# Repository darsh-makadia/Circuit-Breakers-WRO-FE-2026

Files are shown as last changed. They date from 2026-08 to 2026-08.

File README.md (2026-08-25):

# The Dark Knight — Team Current | WRO Future Engineers 2026

> **A reproducible self-driving vehicle developed for WRO Future Engineers 2026**






---

## Contents

- [About the Project](#about-the-project)
- [The Team](#the-team)
- [Final Robot](#final-robot)
- [Hardware and System Overview](#hardware-and-system-overview)
- [Mechanical Design](#mechanical-design)
- [Drivetrain and Differentials](#drivetrain-and-differentials)
- [Steering](#steering)
- [Camera System and Perception](#camera-system-and-perception)
- [Computer Vision Pipeline](#computer-vision-pipeline)
- [Software Architecture](#software-architecture)
- [Open Challenge](#open-challenge)
- [Obstacle Challenge](#obstacle-challenge)
- [Parking Development](#parking-development)
- [Power and Electronics](#power-and-electronics)
- [Testing and Validation](#testing-and-validation)
- [Engineering Evolution](#engineering-evolution)
- [Quick Start](#quick-start)
- [Repository Structure](#repository-structure)
- [Reproducibility](#reproducibility)
- [Evidence Index](#evidence-index)
- [Configuration Consistency](#configuration-consistency)
- [Version and Release](#version-and-release)

---

# About the Project

**The Dark Knight** is Team Current's WRO Future Engineers 2026 self-driving vehicle. The project combines a custom mechanical platform, Raspberry Pi-based control, dual Raspberry Pi Camera Module 3 cameras, colour-based computer vision, an MPU6050 IMU, custom 3D-printed components, and Python software for autonomous navigation.

The robot was developed through multiple mechanical and software iterations rather than as a single fixed design. The repository preserves the final configuration together with the engineering evidence needed to understand how the robot was built, why important design decisions were made, and how the resulting system was tested.

The repository is organised as a connected engineering record:

> **Problem → hypothesis → change → test → measured result → decision**

A judge or another team can begin with this README, follow the construction and setup guides, inspect the source code and CAD/STL files, and then review the photographs, measurements, testing records, engineering evolution, and video evidence.

**Repository:** [Team-Current-WRO-FE-2026](https://github.com/darsh-makadia/Team-Current-WRO-FE-2026)

---

# The Team

<table>
<tr>
<td width="25%" align="center">

Darsh Makadia

### Darsh Makadia
**Team Member**

Mechanical design, hardware integration, software development, testing, and overall robot integration.

</td>
<td width="25%" align="center">

Ehan Mansuri

### Ehan Mansuri
**Team Member**

CAD design, mechanical development, manufactured components, and robot design integration.

</td>
<td width="25%" align="center">

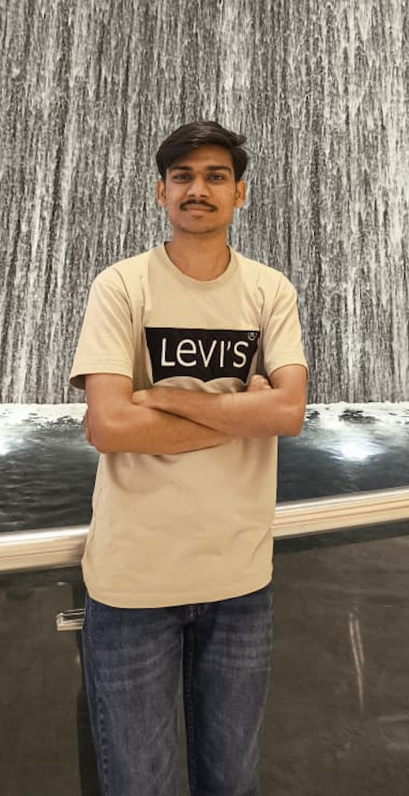
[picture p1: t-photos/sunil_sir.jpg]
Sunil Solanki


### Sunil Solanki
**Coach**

Electrical systems, mechanical guidance, software development, and technical integration guidance.

</td>
<td width="25%" align="center">

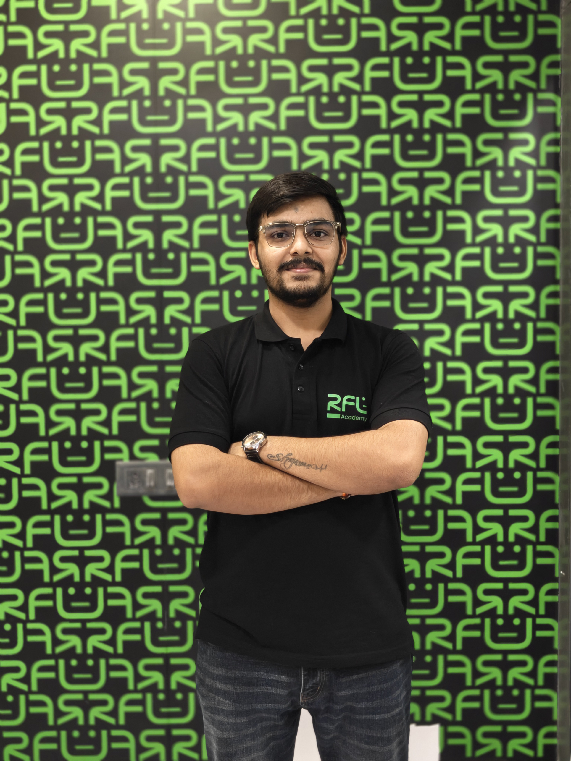
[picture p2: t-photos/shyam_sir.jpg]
Shyam Satasiya


### Shyam Satasiya
**Coach**

CAD guidance and support for mechanical design and manufactured components.

</td>
</tr>
</table>

<p align="center">
Team Current
</p>

---

# Final Robot

The final robot uses a custom 3D-printed chassis and integrates the drivetrain, steering system, cameras, Raspberry Pi, motor electronics, IMU, battery, and electronics enclosure into a compact vehicle.

<table>
<tr>
<td width="33%" align="center">
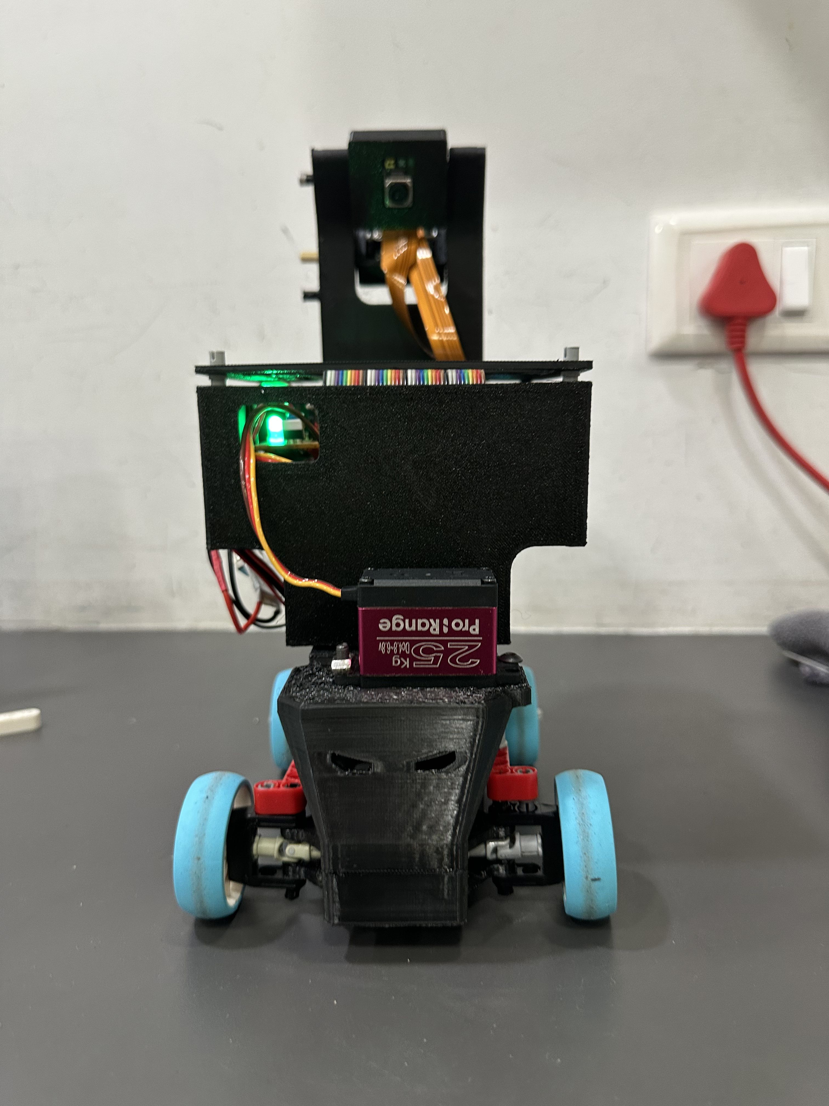
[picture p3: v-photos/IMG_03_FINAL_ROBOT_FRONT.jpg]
Final robot front view

<br><b>Front view</b>
</td>
<td width="33%" align="center">
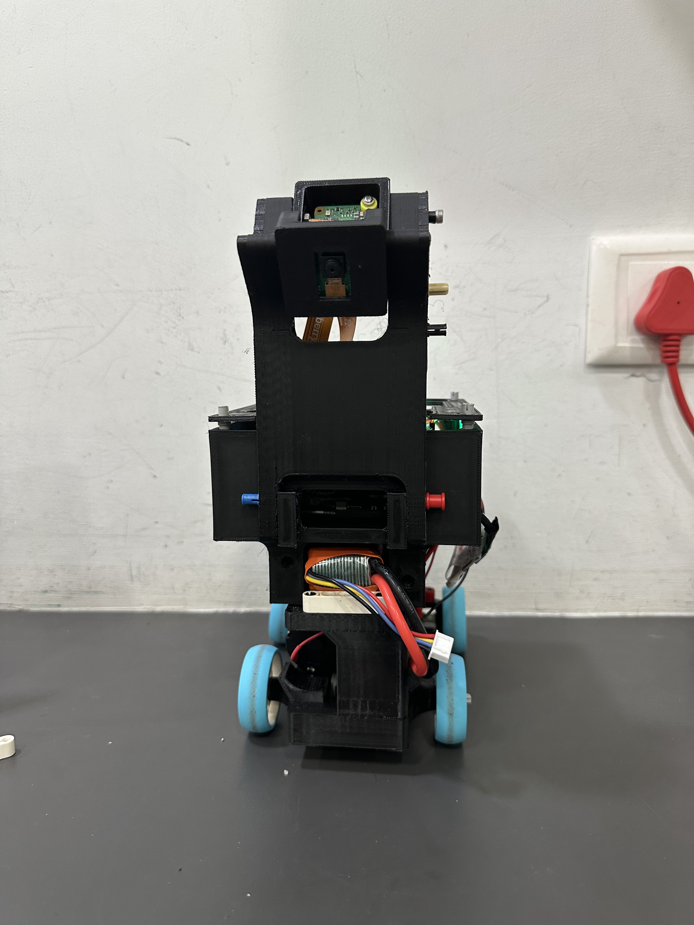
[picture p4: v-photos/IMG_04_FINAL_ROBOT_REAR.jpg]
Final robot rear view

<br><b>Rear view</b>
</td>
<td width="33%" align="center">
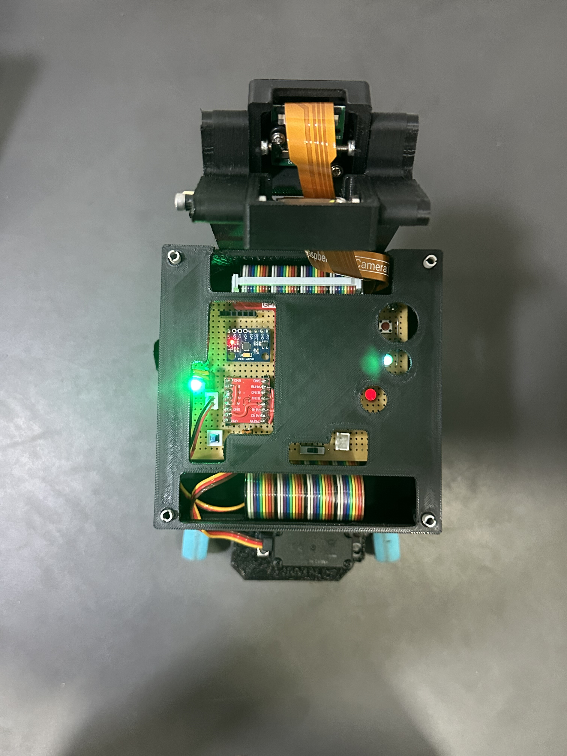
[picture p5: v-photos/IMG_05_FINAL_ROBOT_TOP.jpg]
Final robot top view

<br><b>Top view</b>
</td>
</tr>
</table>

<table>
<tr>
<td width="50%" align="center">
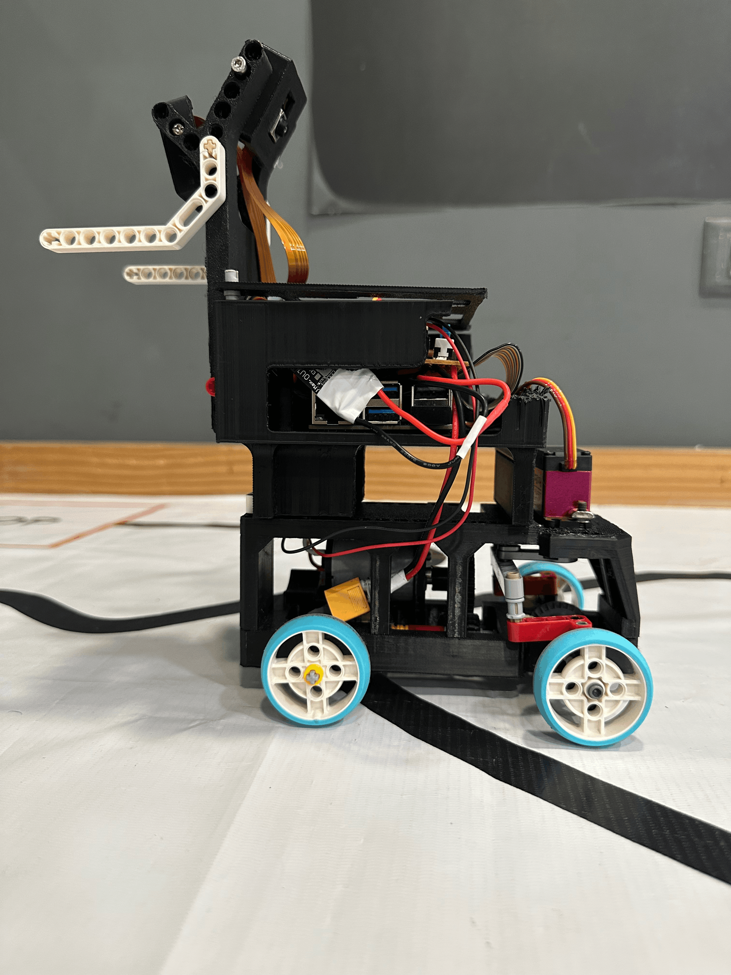
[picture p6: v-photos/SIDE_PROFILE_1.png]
Robot side profile 1

<br><b>Side profile 1</b>
</td>
<td width="50%" align="center">
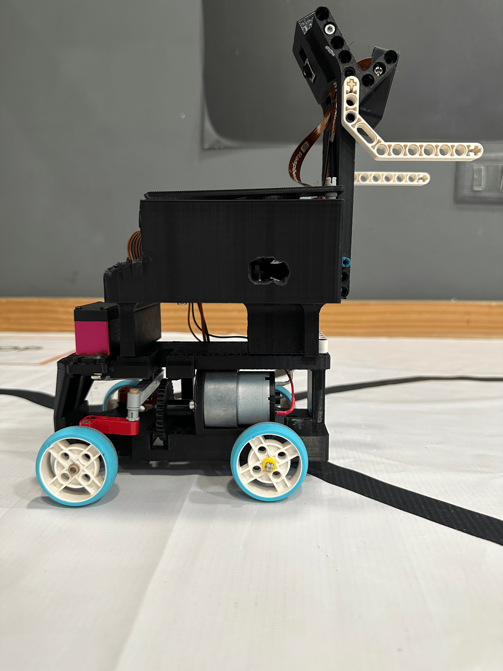
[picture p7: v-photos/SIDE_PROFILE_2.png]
Robot side profile 2

<br><b>Side profile 2</b>
</td>
</tr>
</table>

## Development history

The final configuration was reached through earlier prototypes.

<table>
<tr>
<td width="50%" align="center">
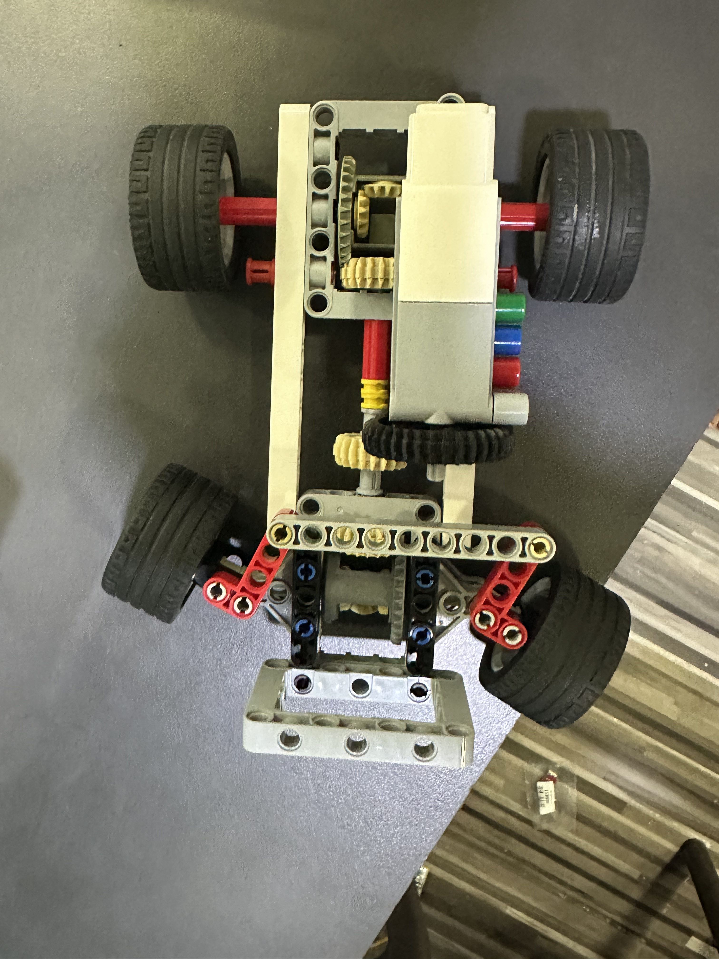
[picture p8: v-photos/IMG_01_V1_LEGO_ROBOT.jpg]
Version 1 LEGO development robot

<br><b>Version 1 — LEGO-heavy development platform</b>
</td>
<td width="50%" align="center">
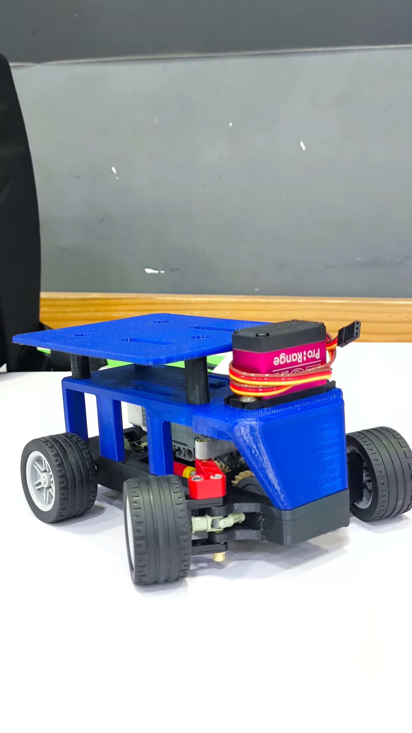
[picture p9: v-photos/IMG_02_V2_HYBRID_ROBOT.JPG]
Version 2 hybrid robot

<br><b>Version 2 — LEGO/CAD hybrid platform</b>
</td>
</tr>
</table>

The progression from a LEGO-heavy prototype to a hybrid platform and then to the final custom chassis is documented in [`testing/engineering_evolution.md`](testing/engineering_evolution.md).

---

# Hardware and System Overview

The robot's main hardware architecture combines:

| Subsystem | Implementation |
|---|---|
| Main computer | Raspberry Pi 5 |
| Cameras | Two Raspberry Pi Camera Module 3 cameras |
| Vision processing | OpenCV-based colour segmentation and contour analysis |
| Heading sensing | MPU6050 through I2C |
| Drive | JGB37-520 DC drive motor |
| Steering | Servo-operated steering mechanism |
| Drivetrain | Central drive arrangement with two axle differentials |
| Battery | 11.1 V battery system |
| Custom components | 3D-printed chassis, camera mount/case, electronics enclosure, and 36-tooth gear |

The exact components and purchase references are documented in [`guide/PARTS_AND_PURCHASE_LINKS.md`](guide/PARTS_AND_PURCHASE_LINKS.md). The construction process is documented in [`guide/BUILD_FROM_ZERO.md`](guide/BUILD_FROM_ZERO.md).

---

# Mechanical Design

The final vehicle uses a custom printed chassis to provide a dedicated structure for the drivetrain, steering system, electronics, cameras, and battery.

## CAD and manufactured components

The final STL files are stored in [`models/`](models/). Their corresponding CAD previews are shown below.

<table>
<tr>
<td width="50%" align="center">
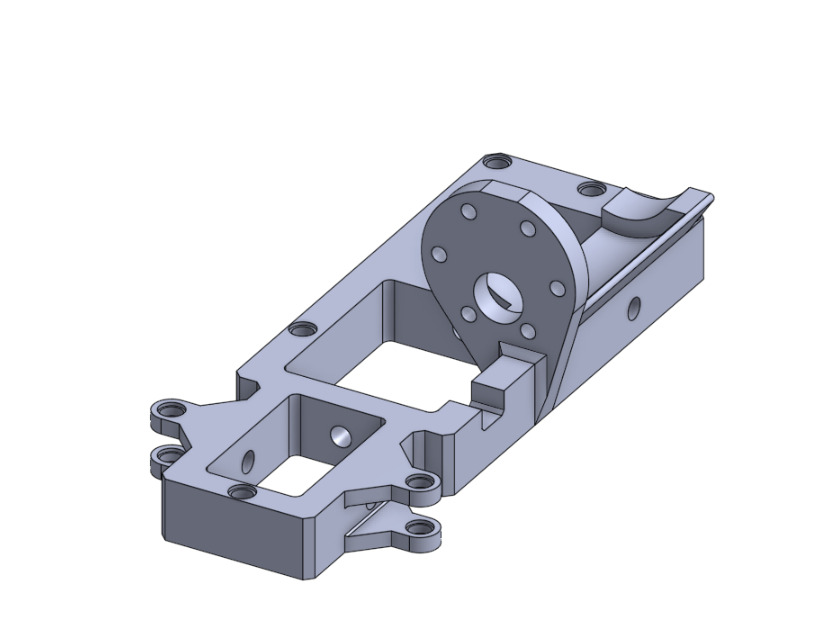
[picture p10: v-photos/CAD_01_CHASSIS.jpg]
CAD chassis

<br><a href="models/chassis.stl"><b>chassis.stl</b></a>
</td>
<td width="50%" align="center">
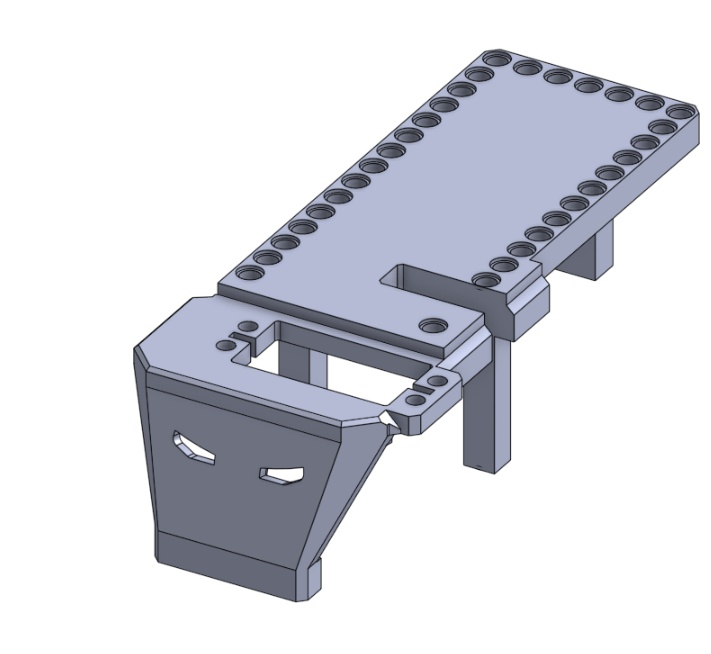
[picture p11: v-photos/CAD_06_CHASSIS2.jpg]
CAD second chassis component

<br><a href="models/chassis%20pt2.stl"><b>chassis pt2.stl</b></a>
</td>
</tr>
<tr>
<td width="50%" align="center">
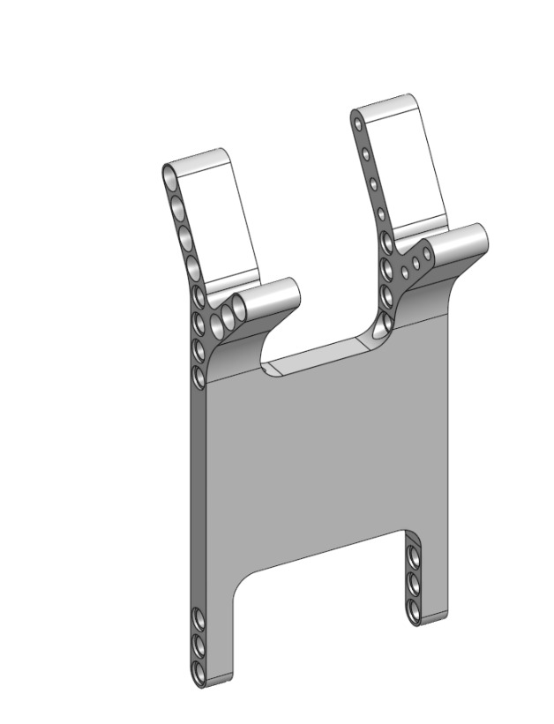
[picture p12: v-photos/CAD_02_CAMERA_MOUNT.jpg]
CAD dual camera mount

<br><a href="models/dual_camera_mount.stl"><b>dual_camera_mount.stl</b></a>
</td>
<td width="50%" align="center">
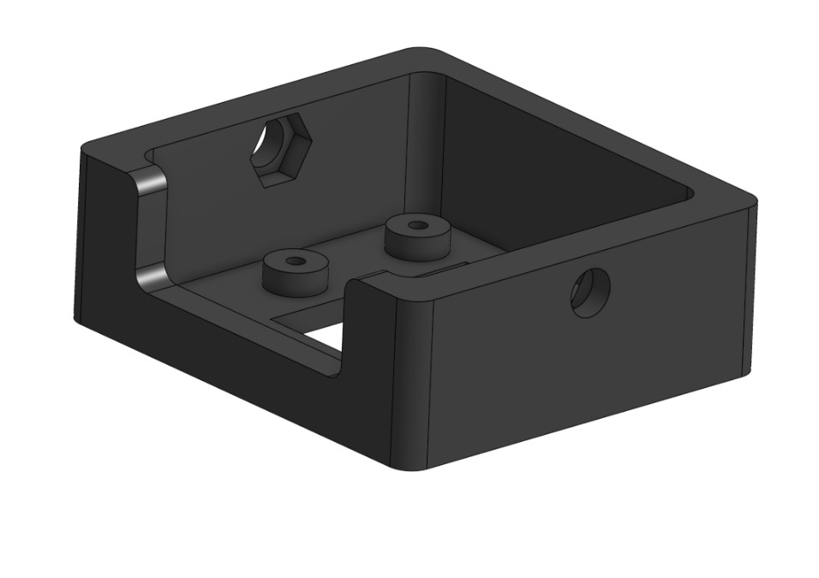
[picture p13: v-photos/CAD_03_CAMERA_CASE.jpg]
CAD camera case

<br><a href="models/camera%20case.stl"><b>camera case.stl</b></a>
</td>
</tr>
<tr>
<td width="50%" align="center">
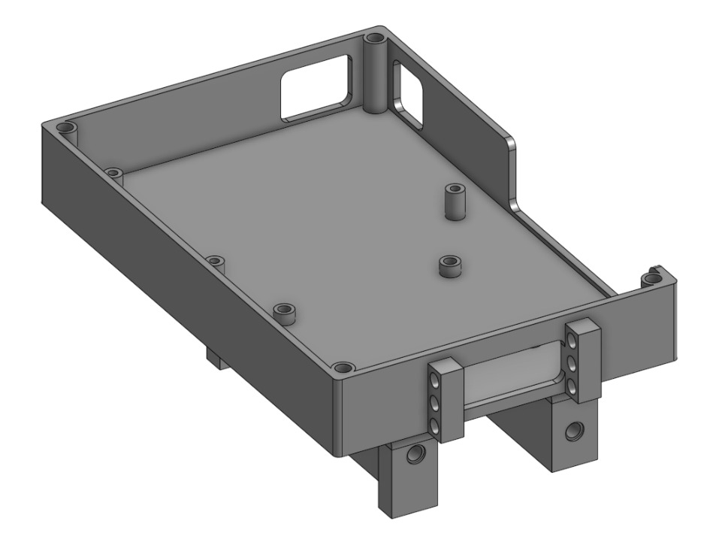
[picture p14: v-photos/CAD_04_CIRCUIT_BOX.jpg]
CAD circuit box

<br><a href="models/Circuit_Box.stl"><b>Circuit_Box.stl</b></a>
</td>
<td width="50%" align="center">
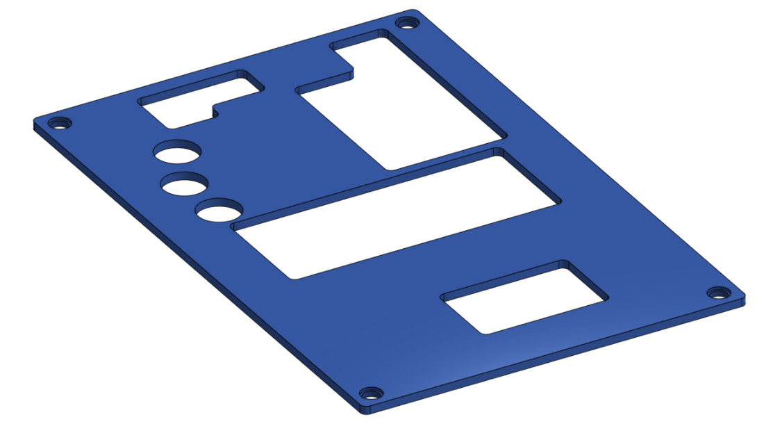
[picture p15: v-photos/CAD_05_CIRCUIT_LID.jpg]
CAD circuit box lid

<br><a href="models/Circuit_Box_LID.stl"><b>Circuit_Box_LID.stl</b></a>
</td>
</tr>
<tr>
<td colspan="2" align="center">
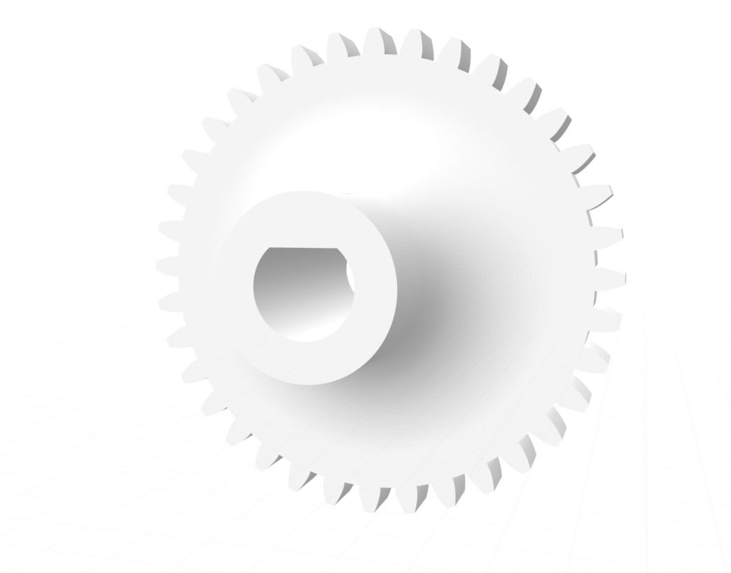
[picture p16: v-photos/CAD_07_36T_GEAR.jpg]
CAD 36 tooth gear

<br><a href="models/36t%20gear.stl"><b>36t gear.stl</b></a>
</td>
</tr>
</table>

Manufacturing settings for the printed components are documented in [`guide/3D_PRINTING_SETTINGS.md`](guide/3D_PRINTING_SETTINGS.md).

---

# Drivetrain and Differentials

The drivetrain uses a central mechanical power path that transfers motion to both axle assemblies. The system includes **two mechanical differentials**, one associated with each axle.

<p align="center">
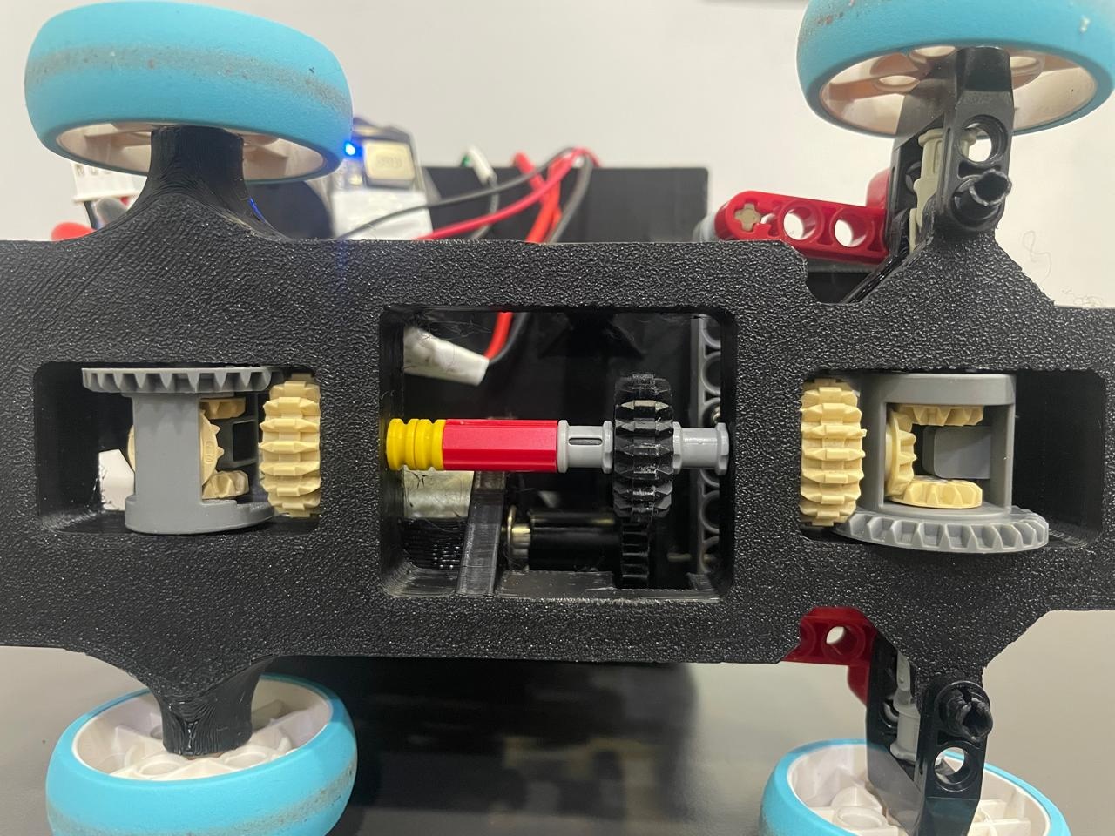
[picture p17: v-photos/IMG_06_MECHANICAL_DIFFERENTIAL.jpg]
Mechanical differential

</p>

The central drivetrain arrangement transfers power through the chassis and distributes it to the axle assemblies.

<p align="center">
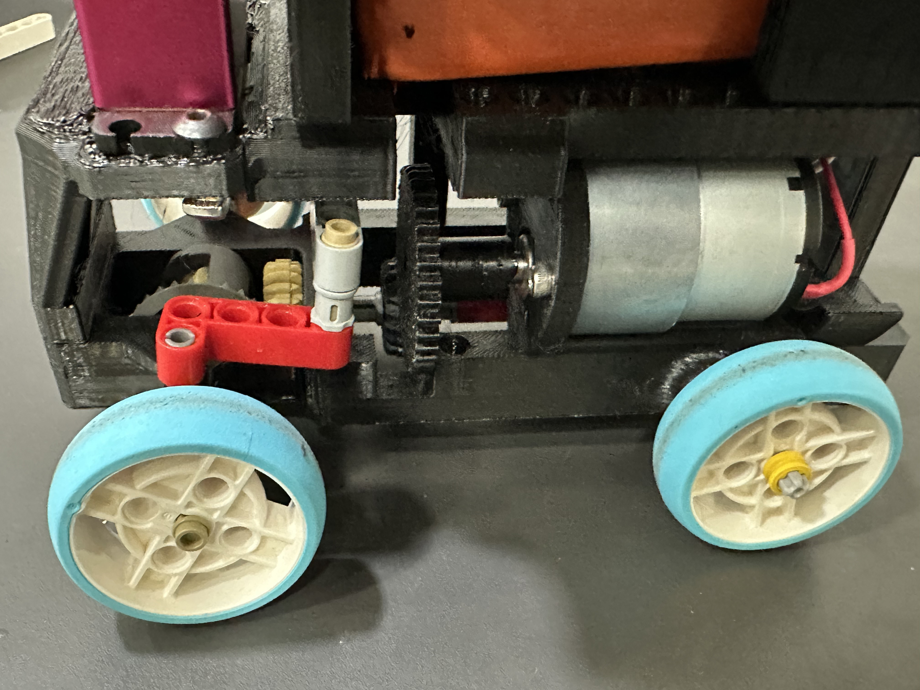
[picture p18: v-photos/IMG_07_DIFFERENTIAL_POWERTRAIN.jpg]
Differential powertrain

</p>

This design allows the drive system to transmit power to all four wheels while retaining differential action at the axle assemblies.

The final drivetrain and motor configuration should be interpreted together with:

- [`guide/BUILD_FROM_ZERO.md`](guide/BUILD_FROM_ZERO.md)
- [`guide/PARTS_AND_PURCHASE_LINKS.md`](guide/PARTS_AND_PURCHASE_LINKS.md)
- [`testing/engineering_evolution.md`](testing/engineering_evolution.md)

---

# Steering

Steering is controlled by a servo-driven mechanical linkage. The steering system was calibrated on the physical robot and integrated with the vehicle-control functions in [`src/drive.py`](src/drive.py).

<p align="center">
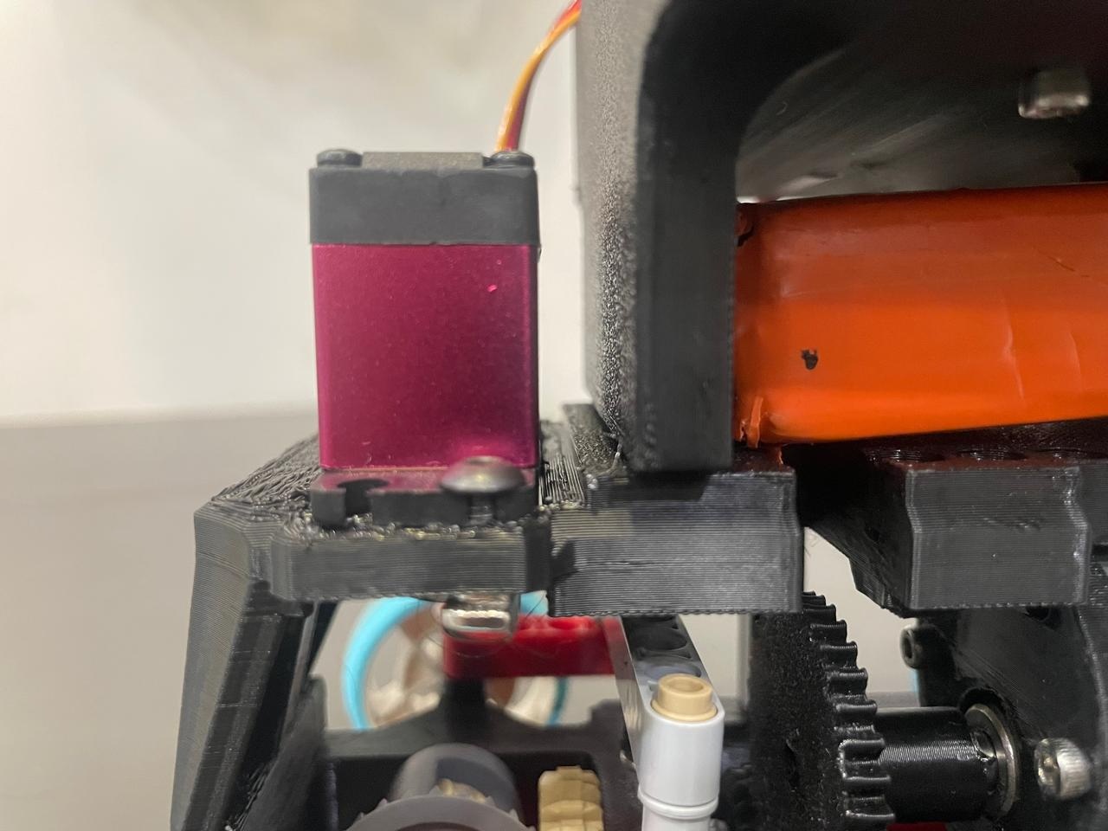
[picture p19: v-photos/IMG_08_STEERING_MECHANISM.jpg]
Steering mechanism

</p>

The software provides steering limits, movement commands, stop behaviour, and GPIO cleanup. Final steering values are controlled by the source configuration and should be verified against the physical robot before a new reproduction or competition configuration is called final.

The drive motor mounting arrangement is shown below.

<p align="center">
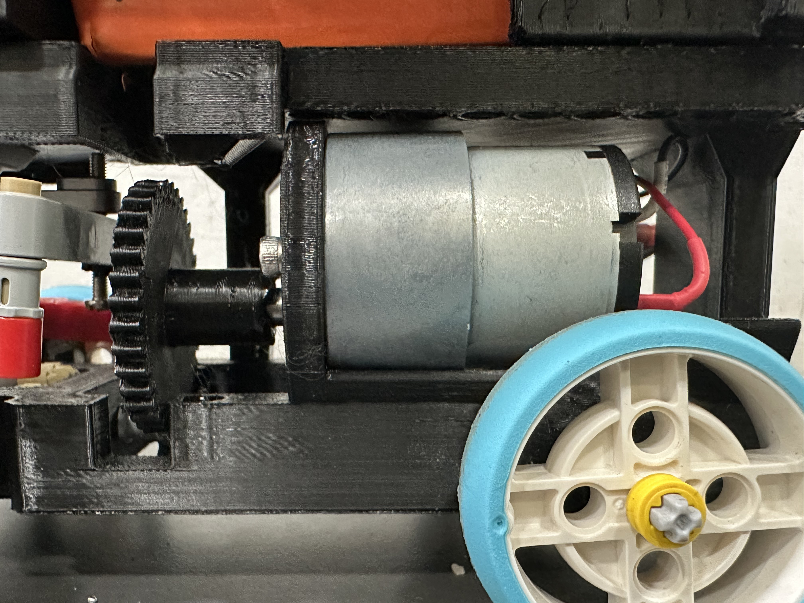
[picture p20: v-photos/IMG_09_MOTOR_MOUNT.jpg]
Motor mount

</p>

---

# Camera System and Perception

The robot uses two Raspberry Pi Camera Module 3 cameras for different perception tasks.

<p align="center">
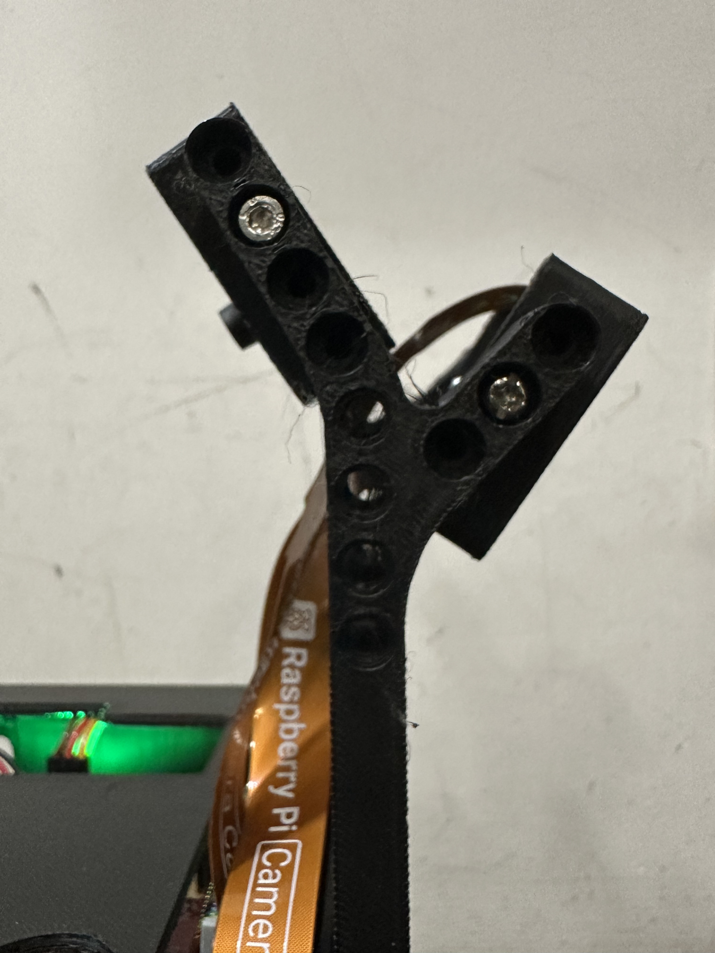
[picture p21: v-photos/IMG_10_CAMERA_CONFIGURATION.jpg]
Camera configuration

</p>

The camera mounting system was adjusted during development to obtain useful fields of view for challenge navigation and parking.

<p align="center">
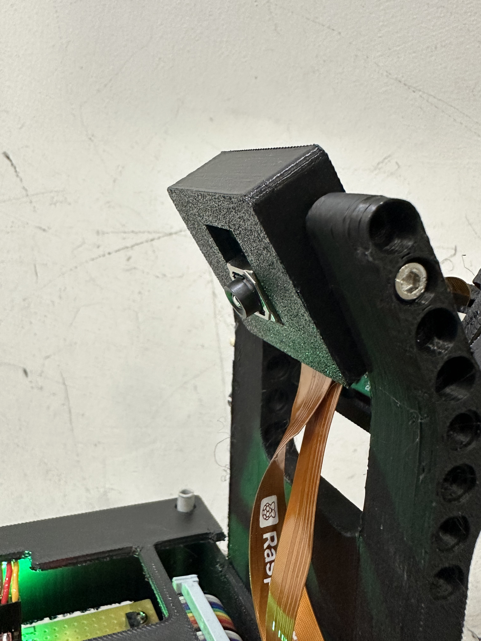
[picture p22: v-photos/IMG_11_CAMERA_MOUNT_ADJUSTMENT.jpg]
Camera mount adjustment

</p>

## Camera evidence

<table>
<tr>
<td width="33%" align="center">
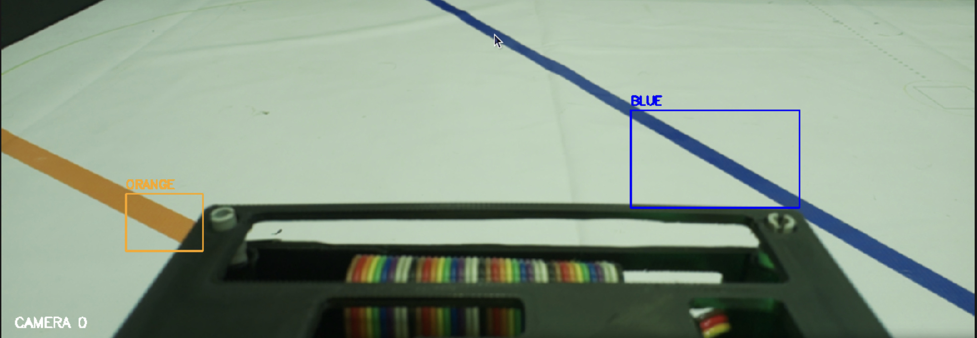
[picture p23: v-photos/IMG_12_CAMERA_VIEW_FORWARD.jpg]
Forward camera view

<br><b>Forward navigation view</b>
</td>
<td width="33%" align="center">
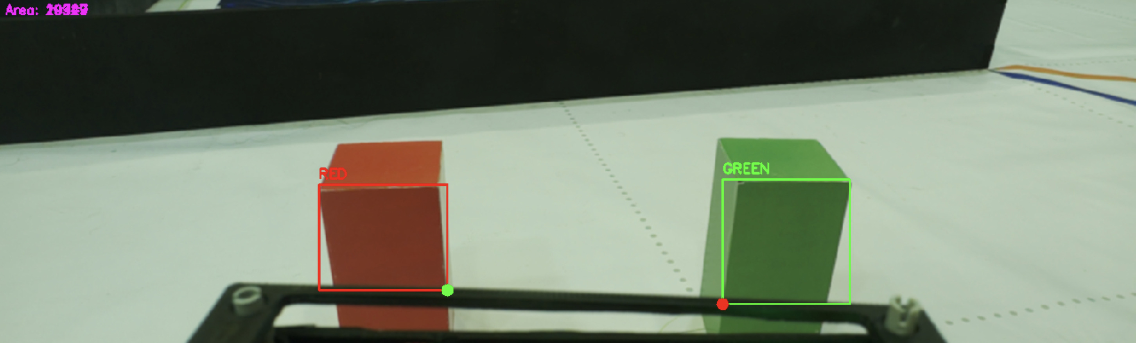
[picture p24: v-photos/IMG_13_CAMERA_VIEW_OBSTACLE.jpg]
Obstacle camera view

<br><b>Obstacle perception view</b>
</td>
<td width="33%" align="center">
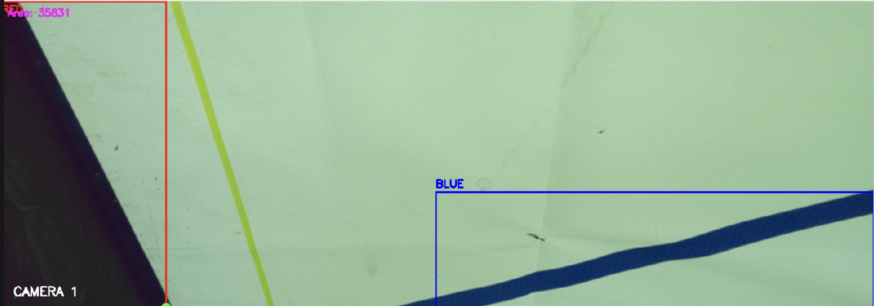
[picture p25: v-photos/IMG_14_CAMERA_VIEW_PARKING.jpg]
Parking camera view

<br><b>Parking perception view</b>
</td>
</tr>
</table>

Both challenge programs currently use the front camera at **1480 × 520 pixels**. The configured target and the measured processing performance are kept separate: the target camera rate is not presented as identical to the observed end-to-end processing rate.

Camera and sensor configuration evidence is documented in [`guide/POWER_AND_SENSOR_EVIDENCE.md`](guide/POWER_AND_SENSOR_EVIDENCE.md).

---

# Computer Vision Pipeline

The vision implementation is based primarily on direct colour segmentation and contour analysis using OpenCV.

The shared processing sequence is:

```text
Camera frame
    ↓
HSV conversion
    ↓
Colour mask
    ↓
Morphological opening/closing
    ↓
Contour extraction
    ↓
Filtering / confidence logic
    ↓
Target point
```

## Open Challenge processing

The Open Challenge uses the relevant camera image and marker-processing logic to determine direction, detect and count markers, support wall following, and determine when the configured challenge sequence is complete.

The Open Challenge-specific vision implementation is contained in [`src/openVision.py`](src/openVision.py), while the main challenge program is [`src/Current_Open_8_22.py`](src/Current_Open_8_22.py).

## Obstacle Challenge processing

The Obstacle Challenge uses colour segmentation and contour processing to identify coloured obstacles and calculate the target information used by the challenge-control logic.

A black segmentation mask is used as evidence for track/boundary isolation:

<p align="center">
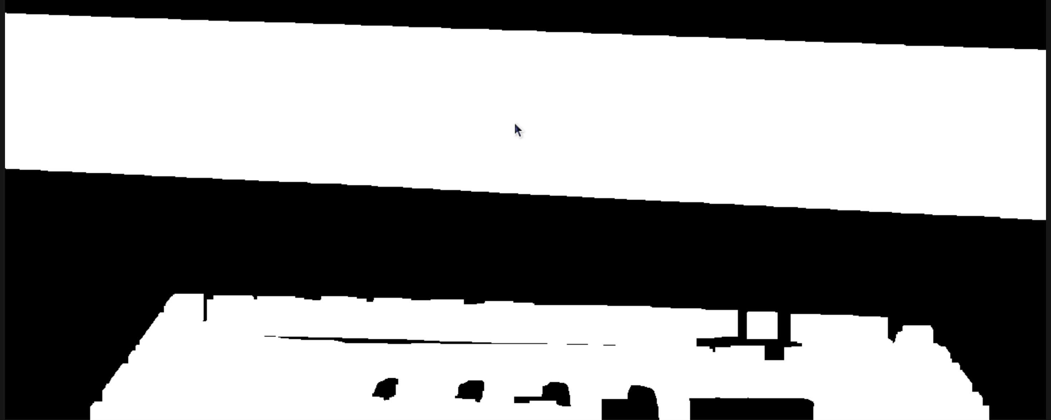
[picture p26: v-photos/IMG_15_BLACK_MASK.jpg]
Black segmentation mask

</p>

Contour processing and obstacle detection evidence are shown below.

<table>
<tr>
<td width="50%" align="center">
Contour detection
<br><b>Contour-processing output</b>
</td>
<td width="50%" align="center">
Obstacle detection
<br><b>Obstacle-detection output</b>
</td>
</tr>
</table>

The shared obstacle-processing implementation is contained in [`src/vision.py`](src/vision.py), while challenge behaviour is controlled by [`src/Current_Obstacle_8_21.py`](src/Current_Obstacle_8_21.py).

---

# Software Architecture

The repository contains the executable Python programs and reusable hardware/software modules in [`src/`](src/).

| File | Function |
|---|---|
| [`Current_Open_8_22.py`](src/Current_Open_8_22.py) | Open Challenge program, direction selection, marker detection/counting, wall following, steering, speed control, and stopping. |
| [`Current_Obstacle_8_21.py`](src/Current_Obstacle_8_21.py) | Obstacle Challenge program, colour-obstacle detection, direction-dependent avoidance, lap/parking transition, and completion behaviour. |
| [`drive.py`](src/drive.py) | Raspberry Pi GPIO motor control, PWM, forward/reverse movement, servo steering, steering limits, stop, and cleanup. |
| [`heading.py`](src/heading.py) | MPU6050 I2C communication, gyro-bias calibration, heading integration, and heading wrapping. |
| [`vision.py`](src/vision.py) | Shared camera processing, colour masks, morphology, contour detection, confidence logic, and target selection. |
| [`openVision.py`](src/openVision.py) | Open Challenge-specific vision processing. |
| [`parking.py`](src/parking.py) | Rear-camera parking detection, wall following, and IMU-guided parking actions. |

The GPIO implementation uses **`RPi.GPIO`**, as reflected by the source import:

```python
import RPi.GPIO as GPIO
```

The MPU6050 communicates through **I2C**.

The repository intentionally lists the actual source filenames rather than generic names such as `open_challenge.py` or `obstacle_challenge.py`. A reproducible configuration should always run and document the source files that actually exist in the final repository.

---

# WRO Challenges

## Open Challenge

The Open Challenge software is implemented in:

[`src/Current_Open_8_22.py`](src/Current_Open_8_22.py)

The program combines:

- direction selection;
- marker detection and counting;
- cooldown and duplicate-detection control;
- wall-following logic;
- steering control;
- speed control; and
- challenge completion/stopping behaviour.

The current source contains the final challenge parameters used for the repository baseline, including:

- `TOTAL_LINES = 13`
- `LINE_COOLDOWN = 1.2`
- `START_SPEED = 40`
- `TARGET_SPEED = 70`

These values should not be replaced in documentation by older values unless the source itself is changed and the resulting configuration is retested.

### Open Challenge evidence

<p align="center">
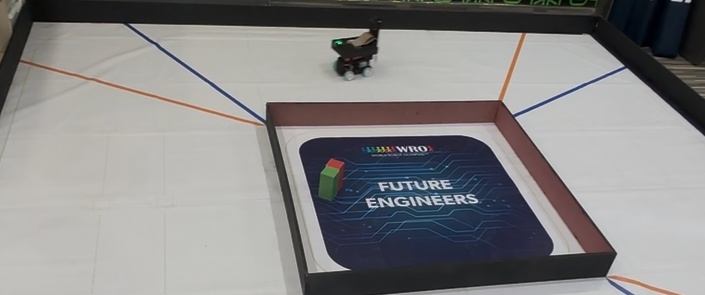
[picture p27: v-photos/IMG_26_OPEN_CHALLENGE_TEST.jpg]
Open Challenge test

</p>

The repository also contains an Open Challenge video in [`testing/Open_Challenge.mp4`](testing/Open_Challenge.mp4) and additional video evidence in [`video/`](video/).

---

## Obstacle Challenge

The Obstacle Challenge software is implemented in:

[`src/Current_Obstacle_8_21.py`](src/Current_Obstacle_8_21.py)

The challenge program combines colour-based obstacle perception with direction-dependent navigation and vehicle control. Supporting functions are provided by the shared vision, drive, and heading modules.

<p align="center">
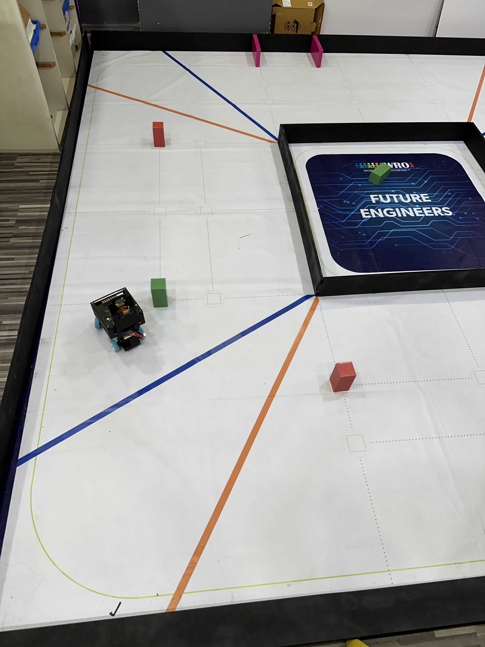
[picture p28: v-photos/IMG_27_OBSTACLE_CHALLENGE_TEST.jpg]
Obstacle Challenge test

</p>

Individual challenge results and observations are stored in [`testing/test_results.csv`](testing/test_results.csv), with a readable summary in [`testing/test_summary.md`](testing/test_summary.md).

Measured processing observations are stored separately in [`testing/processing_observations.csv`](testing/processing_observations.csv). These observations should be interpreted according to the recorded robot configuration and test conditions rather than as a guarantee of an identical processing rate under every possible operating condition.

---

# Parking Development

Parking is an active engineering component of the robot and is represented by:

- [`src/parking.py`](src/parking.py)
- the rear-camera parking view;
- IMU-guided parking actions; and
- dedicated parking test evidence.

<p align="center">
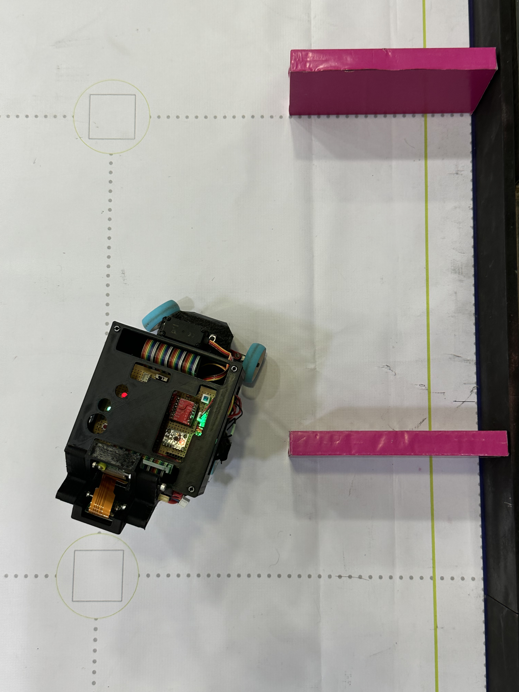
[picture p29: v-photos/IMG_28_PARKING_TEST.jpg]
Parking test

</p>

The parking subsystem is **not presented in this repository as a fully validated final challenge sequence**. Development and testing evidence are retained so that the current implementation, observations, and remaining work are traceable.

Where challenge performance tables or videos exclude parking, they should be interpreted as measuring the completed sequence **up to the parking stage or parking approach**, rather than as proof of a complete run including parallel parking.

This distinction is important for configuration honesty:

> A working Open Challenge and a working obstacle-navigation sequence do not by themselves prove a fully completed Obstacle Challenge with parking.

The current parking implementation and its development evidence remain available for inspection and further improvement.

---

# Power and Electronics

The electrical system distributes power to the Raspberry Pi and logic electronics separately from the motor-control branch.

<p align="center">
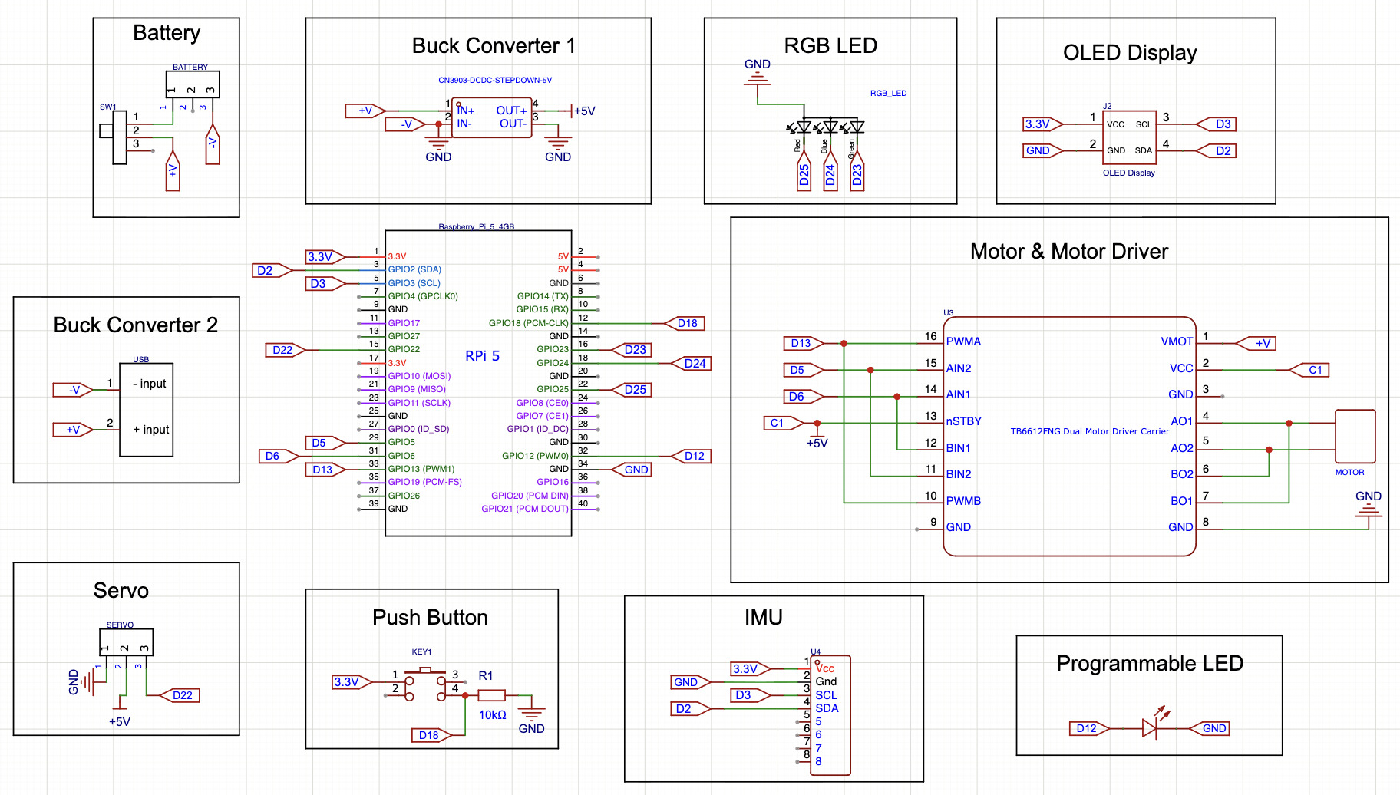
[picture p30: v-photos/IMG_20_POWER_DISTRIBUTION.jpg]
Power distribution

</p>

The electronics enclosure protects and organises the internal components.

<table>
<tr>
<td width="50%" align="center">
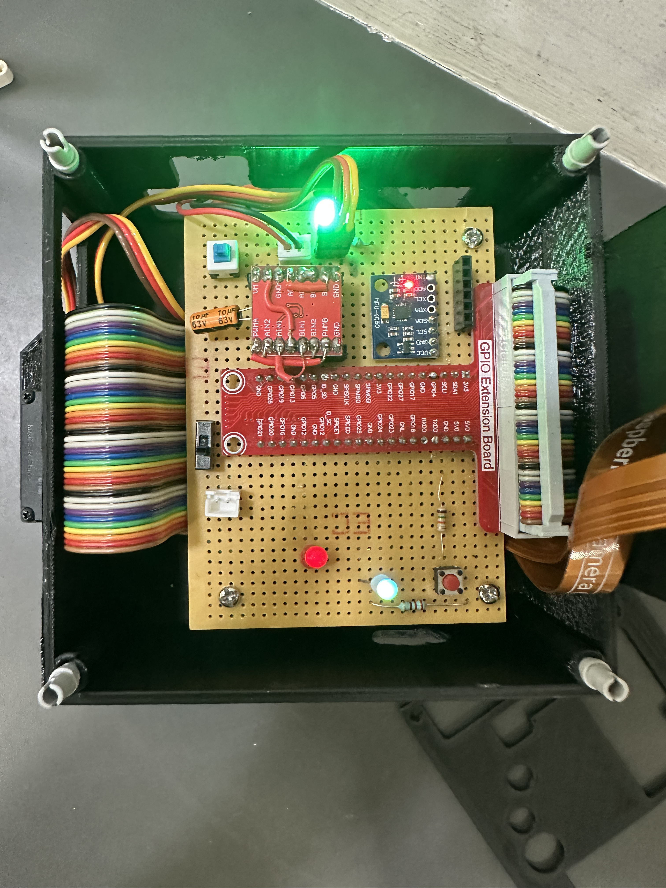
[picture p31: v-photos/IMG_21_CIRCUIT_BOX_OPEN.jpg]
Open circuit box

<br><b>Electronics enclosure — open</b>
</td>
<td width="50%" align="center">
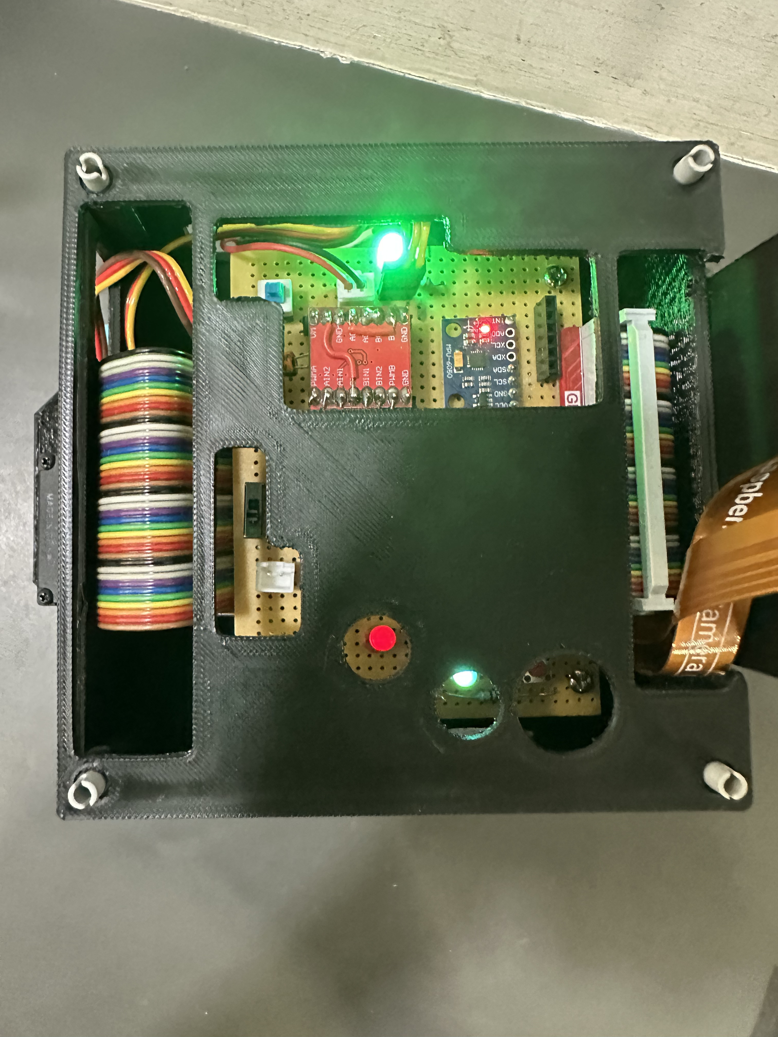
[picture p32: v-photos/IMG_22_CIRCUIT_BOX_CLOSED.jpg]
Closed circuit box

<br><b>Electronics enclosure — closed</b>
</td>
</tr>
</table>

The battery installation is shown below.

<p align="center">
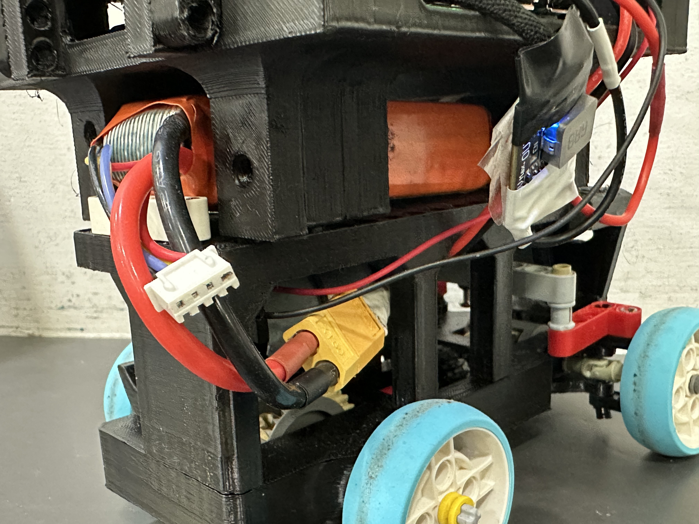
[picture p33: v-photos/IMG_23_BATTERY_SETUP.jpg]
Battery setup

</p>

The final electrical schematic is the primary visual reference for power distribution and signal connections:

<p align="center">
<a href="schemes/schematic.jpg">
Electrical schematic
</a>
</p>

For detailed electrical reproduction, use:

- [`schemes/schematic.jpg`](schemes/schematic.jpg)
- [`guide/WIRING_AND_PIN_REFERENCE.md`](guide/WIRING_AND_PIN_REFERENCE.md)
- [`guide/POWER_AND_SENSOR_EVIDENCE.md`](guide/POWER_AND_SENSOR_EVIDENCE.md)
- [`testing/power_measurements.csv`](testing/power_measurements.csv)

Measured voltages and any current values that were not directly measured are explicitly distinguished in the power evidence rather than being presented as equivalent measurements.

---

# Testing and Validation

Testing evidence is stored in [`testing/`](testing/).

The validation workflow is:

```text
Problem
    ↓
Hypothesis
    ↓
Engineering change
    ↓
Test
    ↓
Measured result
    ↓
Decision
```

## Test records

| File | Evidence |
|---|---|
| [`test_results.csv`](testing/test_results.csv) | Individual Open Challenge and Obstacle Challenge runs, times, and observations. |
| [`test_summary.md`](testing/test_summary.md) | Human-readable summary of challenge results and processing observations. |
| [`engineering_evolution.md`](testing/engineering_evolution.md) | Problems encountered, engineering changes, tests, and resulting decisions. |
| [`power_measurements.csv`](testing/power_measurements.csv) | Measured voltage data and explicit identification of current values that were not directly measured. |
| [`processing_observations.csv`](testing/processing_observations.csv) | Camera FPS, processing loop rate, capture latency, and processing latency observations. |
| [`Open_Challenge.mp4`](testing/Open_Challenge.mp4) | Open Challenge test video stored with testing evidence. |

## Interpreting results correctly

A result is meaningful only within its recorded configuration and conditions. Battery condition, robot configuration, software version, challenge direction, obstacle placement, and test procedure can affect results.

Therefore:

- measurements from different hardware configurations are not automatically treated as identical trials;
- different obstacle placements are not treated as identical challenge conditions;
- configured target rates are not treated as identical to measured end-to-end rates;
- unmeasured current estimates are not presented as direct measurements; and
- performance evidence that excludes parking is not presented as proof of a complete parked sequence.

This distinction is part of the repository's reproducibility standard.

---

# Engineering Evolution

The robot developed through multiple iterations of mechanical, electrical, perception, and software design.

The visual progression is documented from the earlier development platforms to the final robot:

<p align="center">
Version 1
Version 2
Final robot
</p>

The complete engineering record is maintained in [`testing/engineering_evolution.md`](testing/engineering_evolution.md).

This file should be used to trace the important design changes, including mechanical redesign, camera changes, power architecture, steering calibration, vision development, and parking development.

---

# Quick Start

> The exact Raspberry Pi OS version should be confirmed from the final physical robot before a clean reproduction is declared complete.

## 1. Start with the repository guide

Read:

[`guide/START_HERE.md`](guide/START_HERE.md)

This provides the recommended reading order and repository map.

## 2. Obtain the required components

Use:

[`guide/PARTS_AND_PURCHASE_LINKS.md`](guide/PARTS_AND_PURCHASE_LINKS.md)

and verify the final component list against:

[`guide/PARTS_CHECKLIST.md`](guide/PARTS_CHECKLIST.md)

If one file is explicitly designated as the authoritative final list in the repository, that designation should take precedence.

## 3. Build the mechanical platform

Follow:

[`guide/BUILD_FROM_ZERO.md`](guide/BUILD_FROM_ZERO.md)

Download the manufactured part files from:

[`models/`](models/)

Use the documented printing settings in:

[`guide/3D_PRINTING_SETTINGS.md`](guide/3D_PRINTING_SETTINGS.md)

## 4. Complete the electrical system

Use:

- [`schemes/schematic.jpg`](schemes/schematic.jpg)
- [`guide/WIRING_AND_PIN_REFERENCE.md`](guide/WIRING_AND_PIN_REFERENCE.md)

The schematic and pin reference should be checked together rather than treating one image as a complete substitute for the detailed wiring guide.

## 5. Prepare the Raspberry Pi

The source uses:

- Raspberry Pi 5;
- Raspberry Pi Camera Module 3 cameras;
- Python;
- OpenCV;
- NumPy;
- Picamera2;
- `RPi.GPIO`;
- `smbus2`; and
- I2C communication with the MPU6050.

The complete setup procedure belongs in:

[`guide/SOFTWARE_SETUP.md`](guide/SOFTWARE_SETUP.md)

To enable I2C on a fresh Raspberry Pi OS installation:

```bash
sudo raspi-config
```

Then select:

```text
Interface Options → I2C → Enable
```

Reboot after enabling the interface.

The exact Raspberry Pi OS release used for the final configuration can be checked with:

```bash
cat /etc/os-release
```

That version should be copied into the software setup documentation only after it is verified on the physical robot.

## 6. Calibrate and test

Before a challenge run:

1. verify both camera connections;
2. verify I2C communication with the MPU6050;
3. calibrate steering;
4. calibrate the gyro bias and heading behaviour;
5. verify colour-detection thresholds;
6. perform a stationary motor and steering test;
7. perform an Open Challenge test;
8. perform an Obstacle Challenge test; and
9. compare observations with the records in [`testing/`](testing/).

---

# Repository Structure

```text
Team-Current-WRO-FE-2026/
├── README.md
├── CHANGELOG.md
├── .gitattributes
├── .gitignore
│
├── guide/
│   ├── 3D_PRINTING_SETTINGS.md
│   ├── BUILD_FROM_ZERO.md
│   ├── PARTS_AND_PURCHASE_LINKS.md
│   ├── PARTS_CHECKLIST.md
│   ├── POWER_AND_SENSOR_EVIDENCE.md
│   ├── REPRODUCIBILITY_AND_RELEASE_EVIDENCE.md
│   ├── SOFTWARE_SETUP.md
│   ├── START_HERE.md
│   └── WIRING_AND_PIN_REFERENCE.md
│
├── models/
├── schemes/
├── src/
├── testing/
├── t-photos/
├── v-photos/
└── video/
```

## Judge reading path

The recommended path through the repository is:

```text
README.md
→ guide/START_HERE.md
→ guide/BUILD_FROM_ZERO.md
→ guide/PARTS_AND_PURCHASE_LINKS.md
→ guide/WIRING_AND_PIN_REFERENCE.md
→ guide/SOFTWARE_SETUP.md
→ src/
→ models/
→ schemes/schematic.jpg
→ v-photos/
→ testing/
→ video/
→ CHANGELOG.md
```

---

# Detailed Repository Map

## `guide/`

| File | Purpose |
|---|---|
| [`START_HERE.md`](guide/START_HERE.md) | Recommended reading order and repository map. |
| [`BUILD_FROM_ZERO.md`](guide/BUILD_FROM_ZERO.md) | Robot assembly from the parts through testing priorities. |
| [`PARTS_AND_PURCHASE_LINKS.md`](guide/PARTS_AND_PURCHASE_LINKS.md) | Required components and purchase references. |
| [`PARTS_CHECKLIST.md`](guide/PARTS_CHECKLIST.md) | Component checklist. |
| [`WIRING_AND_PIN_REFERENCE.md`](guide/WIRING_AND_PIN_REFERENCE.md) | Power architecture, GPIO assignments, motor-driver connections, servo connection, I2C devices, cameras, steering values, and measured voltages. |
| [`SOFTWARE_SETUP.md`](guide/SOFTWARE_SETUP.md) | Raspberry Pi setup, dependencies, cameras, I2C, source map, calibration, run order, and safety instructions. |
| [`POWER_AND_SENSOR_EVIDENCE.md`](guide/POWER_AND_SENSOR_EVIDENCE.md) | Power branches, voltage evidence, current limitations, sensor selection, calibration, and interference considerations. |
| [`3D_PRINTING_SETTINGS.md`](guide/3D_PRINTING_SETTINGS.md) | Manufacturing settings for custom printed components. |
| [`REPRODUCIBILITY_AND_RELEASE_EVIDENCE.md`](guide/REPRODUCIBILITY_AND_RELEASE_EVIDENCE.md) | Configuration baseline, clean-build workflow, evidence mapping, and release discipline. |

## `models/`

| STL file | Purpose |
|---|---|
| [`chassis.stl`](models/chassis.stl) | Main custom printed chassis. |
| [`chassis pt2.stl`](models/chassis%20pt2.stl) | Additional chassis component. |
| [`dual_camera_mount.stl`](models/dual_camera_mount.stl) | Dual-camera mounting structure. |
| [`camera case.stl`](models/camera%20case.stl) | Camera enclosure. |
| [`Circuit_Box.stl`](models/Circuit_Box.stl) | Electronics enclosure. |
| [`Circuit_Box_LID.stl`](models/Circuit_Box_LID.stl) | Electronics-enclosure lid. |
| [`36t gear.stl`](models/36t%20gear.stl) | Custom 36-tooth drive gear. |

## `schemes/`

| File | Purpose |
|---|---|
| [`schematic.jpg`](schemes/schematic.jpg) | Final electrical schematic and primary visual reference for power and signal connections. |

## `src/`

The executable source code is described in the [Software Architecture](#software-architecture) section above.

## `testing/`

The testing records are described in the [Testing and Validation](#testing-and-validation) section above.

## `t-photos/`

Contains team and individual photographs used in the [Team](#the-team) section.

## `v-photos/`

Contains CAD previews, robot photographs, mechanical evidence, camera/perception evidence, power/electronics evidence, and challenge-testing photographs.

## `video/`

Contains additional local challenge video evidence and [`yt_video_link.md`](video/yt_video_link.md), which identifies the external YouTube video evidence.

---

# Reproducibility

The repository is intended to allow another team or reviewer to trace the final robot from design through validation.

A reproducible reconstruction should be able to follow:

```text
Parts
  ↓
CAD/STL manufacturing
  ↓
Mechanical assembly
  ↓
Electrical schematic and pin wiring
  ↓
Raspberry Pi and software setup
  ↓
Sensor and steering calibration
  ↓
Source-code execution
  ↓
Challenge testing
  ↓
Comparison with recorded evidence
```

The detailed reproducibility procedure is maintained in:

[`guide/REPRODUCIBILITY_AND_RELEASE_EVIDENCE.md`](guide/REPRODUCIBILITY_AND_RELEASE_EVIDENCE.md)

The most important reproducibility principle is:

> **The README, engineering journal, guide files, source code, CAD/STL files, schematic, testing records, and changelog must describe the same final robot configuration. If a parameter or hardware component changes during development, the corresponding source, test record, and documentation are updated together before the configuration is called final.**

The repository therefore treats documentation as part of the engineering configuration rather than as a separate description written after development.

---

# Failure Modes and Mitigation

| Failure mode | Mitigation or engineering response |
|---|---|
| IMU or I2C communication failure | Stop or prevent an uncontrolled manoeuvre according to the implemented safety behaviour. |
| Duplicate marker detection | Use rising-edge detection and a cooldown period. |
| Camera exposure variation | Use the documented exposure and camera configuration procedures. |
| False colour detection | Use colour masks, morphology, contour filtering, geometry/confidence logic, and challenge-specific validation. |
| Motor stall or excessive current | Use the documented motor/power configuration and distinguish measured electrical values from estimates. |
| Excessive speed or wheel lift | Tune operating speed for stability rather than relying on theoretical maximum motor RPM. |
| Wall collision | Record the remaining risk and refine direction-dependent navigation and steering behaviour. |
| Low battery condition | Verify battery condition and documented voltage thresholds before testing. |
| Parking instability | Treat parking as a separate development limitation until the complete sequence is validated. |

Failure handling and engineering limitations should remain consistent across the source code, test records, README, and engineering journal.

---

# Evidence Index

## Final robot and development

- [`IMG_01_V1_LEGO_ROBOT.jpg`](v-photos/IMG_01_V1_LEGO_ROBOT.jpg)
- [`IMG_02_V2_HYBRID_ROBOT.JPG`](v-photos/IMG_02_V2_HYBRID_ROBOT.JPG)
- [`IMG_03_FINAL_ROBOT_FRONT.jpg`](v-photos/IMG_03_FINAL_ROBOT_FRONT.jpg)
- [`IMG_04_FINAL_ROBOT_REAR.jpg`](v-photos/IMG_04_FINAL_ROBOT_REAR.jpg)
- [`IMG_05_FINAL_ROBOT_TOP.jpg`](v-photos/IMG_05_FINAL_ROBOT_TOP.jpg)
- [`SIDE_PROFILE_1.png`](v-photos/SIDE_PROFILE_1.png)
- [`SIDE_PROFILE_2.png`](v-photos/SIDE_PROFILE_2.png)

## Mechanical evidence

- [`IMG_06_MECHANICAL_DIFFERENTIAL.jpg`](v-photos/IMG_06_MECHANICAL_DIFFERENTIAL.jpg)
- [`IMG_07_DIFFERENTIAL_POWERTRAIN.jpg`](v-photos/IMG_07_DIFFERENTIAL_POWERTRAIN.jpg)
- [`IMG_08_STEERING_MECHANISM.jpg`](v-photos/IMG_08_STEERING_MECHANISM.jpg)
- [`IMG_09_MOTOR_MOUNT.jpg`](v-photos/IMG_09_MOTOR_MOUNT.jpg)

## Camera and perception evidence

- [`IMG_10_CAMERA_CONFIGURATION.jpg`](v-photos/IMG_10_CAMERA_CONFIGURATION.jpg)
- [`IMG_11_CAMERA_MOUNT_ADJUSTMENT.jpg`](v-photos/IMG_11_CAMERA_MOUNT_ADJUSTMENT.jpg)
- [`IMG_12_CAMERA_VIEW_FORWARD.jpg`](v-photos/IMG_12_CAMERA_VIEW_FORWARD.jpg)
- [`IMG_13_CAMERA_VIEW_OBSTACLE.jpg`](v-photos/IMG_13_CAMERA_VIEW_OBSTACLE.jpg)
- [`IMG_14_CAMERA_VIEW_PARKING.jpg`](v-photos/IMG_14_CAMERA_VIEW_PARKING.jpg)
- [`IMG_15_BLACK_MASK.jpg`](v-photos/IMG_15_BLACK_MASK.jpg)
- [`IMG_17_CONTOUR_DETECTION.jpg`](v-photos/IMG_17_CONTOUR_DETECTION.jpg)
- [`IMG_18_OBSTACLE_DETECTION.jpg`](v-photos/IMG_18_OBSTACLE_DETECTION.jpg)

## Power and electronics evidence

- [`IMG_20_POWER_DISTRIBUTION.jpg`](v-photos/IMG_20_POWER_DISTRIBUTION.jpg)
- [`IMG_21_CIRCUIT_BOX_OPEN.jpg`](v-photos/IMG_21_CIRCUIT_BOX_OPEN.jpg)
- [`IMG_22_CIRCUIT_BOX_CLOSED.jpg`](v-photos/IMG_22_CIRCUIT_BOX_CLOSED.jpg)
- [`IMG_23_BATTERY_SETUP.jpg`](v-photos/IMG_23_BATTERY_SETUP.jpg)

## Challenge and parking evidence

- [`IMG_26_OPEN_CHALLENGE_TEST.jpg`](v-photos/IMG_26_OPEN_CHALLENGE_TEST.jpg)
- [`IMG_27_OBSTACLE_CHALLENGE_TEST.jpg`](v-photos/IMG_27_OBSTACLE_CHALLENGE_TEST.jpg)
- [`IMG_28_PARKING_TEST.jpg`](v-photos/IMG_28_PARKING_TEST.jpg)

## Team evidence

- [`Darsh_Individual.png`](t-photos/Darsh_Individual.png)
- [`Ehan_Individual.png`](t-photos/Ehan_Individual.png)
- [`Team.png`](t-photos/Team.png)
- [`sunil_sir.jpg`](t-photos/sunil_sir.jpg)
- [`shyam_sir.jpg`](t-photos/shyam_sir.jpg)

---

# Configuration Consistency

Before a configuration is described as final, verify:

| Check | Required result |
|---|---|
| README links | Every link opens an existing file or directory. |
| Image paths | Capitalisation and extensions match the repository exactly. |
| Source map | Every listed Python file exists and has the described purpose. |
| Guide map | Every guide link uses the actual current filename. |
| Schematic | Uses [`schemes/schematic.jpg`](schemes/schematic.jpg). |
| Software values | README values match the actual final source code. |
| Test values | Documentation matches the CSV records and labels the relevant conditions. |
| Camera configuration | Resolution and target/observed performance are not confused. |
| Parking status | Remaining limitations are stated consistently across all evidence. |
| Electrical evidence | Measured values and estimates are explicitly distinguished. |
| Final baseline | A specific final commit or tag identifies the Nationals configuration. |

Generated Python files such as `__pycache__/` and `*.pyc` should remain excluded through `.gitignore` and should not be treated as final reproducibility evidence.

---

# Version and Release

This README describes the repository structure and robot configuration represented by the project baseline.

The repository development history is recorded in:

[`CHANGELOG.md`](CHANGELOG.md)

The final Nationals configuration should be frozen at one identifiable Git commit or tag before submission. That release identity should be recorded consistently in:

- the GitHub repository;
- the changelog;
- the reproducibility/release guide; and
- any final engineering documentation that identifies a fixed configuration.

Meaningful commits make the engineering history easier to trace. Examples include:

```text
mechanical: revise camera mount
vision: improve obstacle confidence
drive: update steering limits
testing: record obstacle challenge runs
docs: update Nationals configuration
```

The repository should not rely on a moving `main` branch alone to identify a final competition configuration once submission evidence is frozen.

---

# Repository Navigation

**Start here:**

➡️ [`guide/START_HERE.md`](guide/START_HERE.md)

Then follow:

**Build** → [`guide/BUILD_FROM_ZERO.md`](guide/BUILD_FROM_ZERO.md)  
**Parts** → [`guide/PARTS_AND_PURCHASE_LINKS.md`](guide/PARTS_AND_PURCHASE_LINKS.md)  
**Wiring** → [`guide/WIRING_AND_PIN_REFERENCE.md`](guide/WIRING_AND_PIN_REFERENCE.md)  
**Software** → [`guide/SOFTWARE_SETUP.md`](guide/SOFTWARE_SETUP.md)  
**Source code** → [`src/`](src/)  
**CAD/STL files** → [`models/`](models/)  
**Electrical schematic** → [`schemes/schematic.jpg`](schemes/schematic.jpg)  
**Robot evidence** → [`v-photos/`](v-photos/)  
**Testing evidence** → [`testing/`](testing/)  
**Video evidence** → [`video/`](video/)  
**Development history** → [`CHANGELOG.md`](CHANGELOG.md)

## Final Evaluated Version

The final repository configuration is frozen under the GitHub release and tag `v1.0.0-nationals`. The release identifies the exact source, guides, CAD/STL files, schematic, testing evidence, photographs, and video evaluated for the WRO Future Engineers 2026 submission.

---

<p align="center">
  <b>Team Current</b><br>
  <i>The Dark Knight — WRO Future Engineers 2026</i>
</p>

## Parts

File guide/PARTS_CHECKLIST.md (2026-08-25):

# Parts checklist — The Dark Knight

Use this before starting a build. The quantities below are only stated where the engineering document explicitly supports them.

## Electronics

| Qty | Part | Final specification |
|---:|---|---|
| 1 | Raspberry Pi | Pi 5, 4 GB |
| 2 | Camera | Raspberry Pi Camera Module 3 |
| 1 | Drive motor | JGB37-520, 12 V, 600 RPM |
| 1 | Steering servo | Servo motor; final software range 35°–115° |
| 1 | Motor driver | TB6612FNG |
| 1 | IMU | MPU6050 |
| 1 | Battery pack | 3S LiPo, 2200 mAh, 11.1 V nominal |
| 2 | Buck converters | Buck 1: 5 V logic/servo rail; Buck 2: 5 V / 5 A Pi rail |
| 1 | OLED | Documented accessory |
| 1 | RGB LED | Documented accessory |
| 1 | Programmable LED | Documented accessory |
| 1 | Push button | Start input |

## Printed parts

| Qty | Part | File |
|---:|---|---|
| 1 | Main chassis | `cad/final_chassis.stl` |
| 1 | Chassis part 2 | `cad/Final chassis — Part 2.stl` |
| 1 | Dual-camera mount | `cad/dual_camera_mount.stl` |
| 1 | Camera case | `cad/camera_case.stl` |
| 1 | Circuit box | `cad/circuit_box.stl` |
| 1 | Circuit box lid | `cad/circuit_box_lid.stl` |
| 1 | Custom drivetrain gear | 36-tooth printed gear; included in the CAD set/reference |

## LEGO mechanical parts

The final document explicitly identifies these component types. It does **not** give a verified quantity for every item, so quantities are deliberately left blank rather than invented.

- 2X4 L beam
- 9 beam
- bush
- half bush
- 2L axle connector
- 5L axle
- 6L axle
- 4L axle with stop
- 28-tooth differential × two axle assemblies
- 24-tooth gear
- 20-tooth gear
- 12-tooth bevel gear
- smooth pin
- friction pin
- universal joint
- 3L friction pin

## Manufacturing

- PLA filament
- Anycubic Cobra 2 Neo 3D printer

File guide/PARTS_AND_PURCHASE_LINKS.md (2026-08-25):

# Parts and Purchase Links

Full component list for reproducing The Dark Knight, with the links actually used to source each part. Prices/availability may change — links are current as of this repository's last update.

## Electronics

| Component | Link |
|---|---|
| Raspberry Pi 5, 4 GB | [robu.in](https://robu.in/product/raspberry-pi-5-model-4gb/) |
| Raspberry Pi Camera Module 3 Wide (×2 — front + back) | [robu.in](https://robu.in/product/raspberry-pi-camera-module-3-wide/) |
| Servo — DS3225 25kg-cm metal gear digital servo | [robu.in](https://robu.in/product/pro-range-ds3225-25kgcm-metal-gear-digital-servo-motor-180-degree/) |
| Motor driver — TB6612FNG module | [robu.in](https://robu.in/product/motor-driver-tb6612fng-module-performance-ultra-small-volume-3-pi-matching-performance-ultra-l298n/) |
| Drive motor — JGB37-520 DC 12V | [robu.in](https://robu.in/product/jgb37-520-dc12v-miniature-forward-and-reverse-brushed-dc-speed-reducer-motor/) |
| Buck converter — 5V/3A (servo + motor driver logic rail) | [robu.in](https://robu.in/product/ultra-small-size-dc-dc-5v-3a-bec-power-supply-buck-step-down-module/) |
| Buck converter — Raspberry Pi rail (5V/5A) | **Not yet sourced — link pending** |
| Battery — 3S LiPo, 11.1V, 2200 mAh | [Amazon.in](https://www.amazon.in/PRAYOG-INDIA-ROBOTICS-Rechargeable-Connector/dp/B0H9L6B694) |
| Battery balance charger | [Amazon.in](https://www.amazon.in/Pro3D-B6-AC-Battery-Balance-Charger/dp/B0CV9H28MQ) |
| MicroSD card (Raspberry Pi OS) | [Amazon.in](https://www.amazon.in/gp/product/B08L5HMJVW) |
| Micro HDMI to HDMI cable | [robu.in](https://robu.in/product/micro-hdmi-male-to-standard-hdmi-male-cable-for-raspberry-pi-4/) |
| IMU — MPU6050 (10DOF module, gyro + accelerometer + magnetometer + barometer) | [robu.in](https://robu.in/product/mpu6050hmc5883lbmp180-10dof-3-axis-gyro-3-axis-acceleration-3-axis-magnetic-field-air-pres/) |
| OLED display — 0.96" I2C/IIC, 4-pin | [robu.in](https://robu.in/product/0-96-inch-i2c-iic-oled-lcd-module-4pin-with-vcc-gnd-white/) |

## Optional / development-only

| Component | Link | Note |
|---|---|---|
| Keyboard + mouse | [Amazon.in](https://www.amazon.in/gp/product/B0BHYJ8CVF) | Not required on the competition robot — used during development for direct Pi access |

## Structural / manufacturing

| Item | Note |
|---|---|
| PLA filament | Generic PLA — see [`3D_PRINTING_SETTINGS.md`](3D_PRINTING_SETTINGS.md) for print profile |
## LEGO Technic Components

Used in the differential, external gearing, and drivetrain axle assembly. Links go to BrickLink catalog listings.

| Component | Link |
|---|---|
| 2×4 L Beam | [BrickLink](https://www.bricklink.com/v2/catalog/catalogitem.page?P=32140) |
| Half bush | [BrickLink](https://www.bricklink.com/v2/catalog/catalogitem.page?P=4265c&idColor=3) |
| Bush | [BrickLink](https://www.bricklink.com/v2/catalog/catalogitem.page?P=3713) |
| 2L axle connector | [BrickLink](https://www.bricklink.com/v2/catalog/catalogitem.page?P=6538c) |
| 28-tooth differential | [BrickLink](https://www.bricklink.com/v2/catalog/catalogitem.page?P=73071) |
| 24-tooth gear | [BrickLink](https://www.bricklink.com/v2/catalog/catalogitem.page?P=3648) |
| 20-tooth gear | [BrickLink](https://www.bricklink.com/v2/catalog/catalogitem.page?P=32269) |
| 12-tooth bevel gear | [BrickLink](https://www.bricklink.com/v2/catalog/catalogitem.page?P=6589) |
| 9-unit beam | [BrickLink](https://www.bricklink.com/v2/catalog/catalogitem.page?P=40490) |
| 5L axle | [BrickLink](https://www.bricklink.com/v2/catalog/catalogitem.page?id=540&idColor=86) |
| 6L axle | [BrickLink](https://www.bricklink.com/v2/catalog/catalogitem.page?P=3706&idColor=60) |
| 4L axle with stop | [BrickLink](https://www.bricklink.com/v2/catalog/catalogitem.page?id=90241&idColor=85) |
| Smooth pin | [BrickLink](https://www.bricklink.com/v2/catalog/catalogitem.page?P=3673) |
| Universal joint | [BrickLink](https://www.bricklink.com/v2/catalog/catalogitem.page?P=62520c01) |
| LEGO Technic wheel 43×14, medium azure tire | [BrickLink](https://www.bricklink.com/v2/catalog/catalogitem.page?P=65834pb02) |

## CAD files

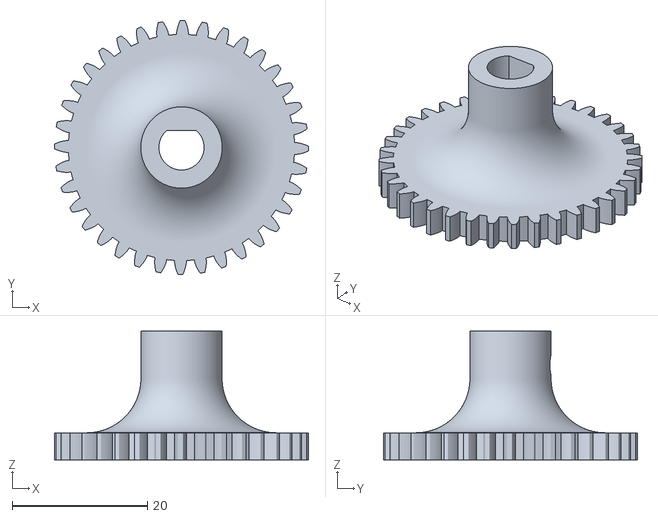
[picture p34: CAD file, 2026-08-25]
models/36t gear.stl
37.5 x 37.5 x 19.0

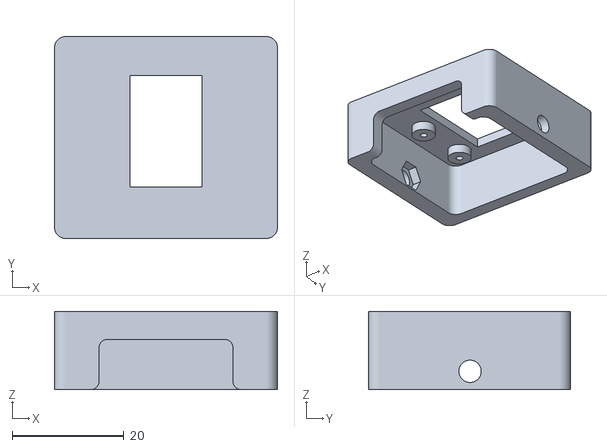
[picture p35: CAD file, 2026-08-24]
models/camera case.stl
40.0 x 36.2 x 14.0

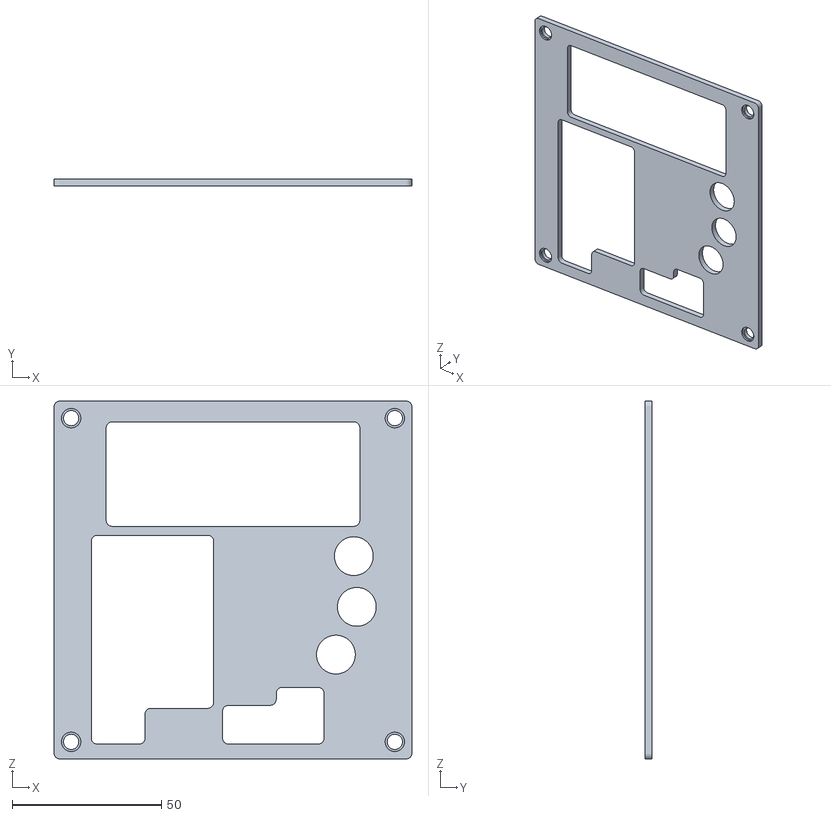
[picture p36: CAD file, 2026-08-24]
models/Circuit_Box_LID.stl
120.0 x 2.50 x 120.0

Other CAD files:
models/dual_camera_mount.stl

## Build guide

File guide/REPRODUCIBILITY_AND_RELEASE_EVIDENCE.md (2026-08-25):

# Reproducibility & Release Evidence
## WRO Future Engineers 2026 — Team Current

This document records the versioned robot configuration and provides a reproducibility path from the repository files to the documented challenge-validation results.

---

## 1. Versioned Nationals Baseline

**Release:** v1.1 — Nationals Evidence Update

The documented baseline is:

- 4WD drivetrain
- Two mechanical LEGO differentials
- Central driveshaft
- Two Raspberry Pi Camera Module 3 cameras
- Raspberry Pi 5 (4 GB)
- MPU6050 IMU
- JGB37-520 12 V 600 RPM drive motor
- TB6612FNG motor driver
- 3S 2200 mAh LiPo battery
- CAD-designed PLA structural parts
- Servo steering
- Python + OpenCV software

Any change after this baseline must be recorded in the repository documentation and, where relevant, reflected in the corresponding source code, configuration, or test evidence.

---

## 2. Repository Structure

```text
Team-Current-WRO-FE-2026/
├── README.md
├── CHANGELOG.md
├── guide/
│   ├── START_HERE.md
│   ├── BUILD_FROM_ZERO.md
│   ├── WIRING_AND_PIN_REFERENCE.md
│   ├── POWER_AND_SENSOR_EVIDENCE.md
│   ├── 3D_PRINTING_SETTINGS.md
│   ├── REPRODUCIBILITY_AND_RELEASE_EVIDENCE.md
│   └── additional build and software documentation
├── models/
├── schemes/
├── src/
├── testing/
├── v-photos/
├── t-photos/
└── video/
```

The repository separates build instructions, electrical and sensor evidence, source code, CAD/STL files, schematics, testing evidence, robot photographs, team photographs, and challenge video material.

---

## 3. Source-to-Function Mapping

| File | Function |
| --- | --- |
| `src/Current_Open_8_22.py` | Open Challenge program |
| `src/Current_Obstacle_8_21.py` | Obstacle Challenge program |
| `src/drive.py` | Motor and steering control |
| `src/heaeding.py` | MPU6050 heading and calibration |
| `src/vision.py` | Camera and colour/target processing |
| `src/openVision.py` | Open Challenge vision processing |
| `src/parking.py` | Parking state machine and IMU-guided turns |

The unusual filename `heaeding.py` is retained because it is the actual repository filename.

---

## 4. Hardware-to-Evidence Mapping

| Hardware or subsystem | Evidence location |
| --- | --- |
| Custom chassis | `models/` + `v-photos/` |
| Drivetrain and differentials | `guide/BUILD_FROM_ZERO.md` + `v-photos/` |
| Camera mount and camera case | `models/` + `v-photos/` |
| Circuit enclosure | `models/` + `v-photos/` |
| 3D-printing configuration | `guide/3D_PRINTING_SETTINGS.md` |
| Wiring and GPIO configuration | `guide/WIRING_AND_PIN_REFERENCE.md` |
| Power and sensor architecture | `guide/POWER_AND_SENSOR_EVIDENCE.md` |
| Final electrical schematic | `schemes/` |
| Final robot views | `v-photos/` |
| Team photographs | `t-photos/` |
| Final STL exports | `models/` |
| Challenge programs | `src/` |
| Testing evidence | `testing/` |
| Challenge video evidence | `video/` |

---

## 5. Reproduction Workflow

The repository is organised so that a new builder can reproduce the documented configuration by following the stages below.

### Step 1 — Prepare the Printed Parts

Use:

- [`3D_PRINTING_SETTINGS.md`](3D_PRINTING_SETTINGS.md)
- The final STL files in [`models/`](../models/)

The printing guide documents the OrcaSlicer baseline, rapid-testing configuration, and stronger final-print configuration.

### Step 2 — Assemble the Robot

Follow:

[`BUILD_FROM_ZERO.md`](BUILD_FROM_ZERO.md)

This guide documents the drivetrain, differentials, external gear stage, chassis, steering, camera placement, electronics integration, and initial software setup.

### Step 3 — Complete the Electrical System

Follow:

- [`WIRING_AND_PIN_REFERENCE.md`](WIRING_AND_PIN_REFERENCE.md)
- [`POWER_AND_SENSOR_EVIDENCE.md`](POWER_AND_SENSOR_EVIDENCE.md)
- The final schematic in [`schemes/`](../schemes/)

The documented architecture keeps the Raspberry Pi on a separate regulated 5 V branch while the motor driver receives the battery-side motor supply. All branches share a common ground.

### Step 4 — Set Up the Software

Use the source files in [`src/`](../src/) and install the documented Raspberry Pi software dependencies.

The project uses Python with the Raspberry Pi camera and hardware stack, including:

- OpenCV
- NumPy
- RPi.GPIO
- Picamera2
- MPU6050 I2C communication

Confirm that both cameras, the MPU6050, motor control, and steering control operate before running a challenge program.

### Step 5 — Calibrate the Robot

Before challenge testing:

1. Verify camera orientation and mounting position.
2. Calibrate vision thresholds on the physical field.
3. Perform stationary MPU6050 gyro calibration.
4. Verify steering centre and steering limits.
5. Verify marker counting and cooldown behaviour.
6. Verify safe-stop behaviour for sensor or control failures.

### Step 6 — Validate the Open Challenge

Run repeated trials and record:

- Selected direction
- Marker detections
- Lap count
- Completion status
- Total time
- Failure mode, if unsuccessful

The documented best result is:

**28 s across six recorded runs.**

### Step 7 — Validate the Obstacle Challenge

Run repeated trials and record:

- Obstacle detection
- Avoidance decision
- Selected direction
- Obstacle-sequence completion
- Transition toward the parking area
- Total time
- Failure mode, if unsuccessful

The documented best result is:

**1:09 across six recorded runs.**

The six recorded obstacle runs measure the documented obstacle sequence without including a completed parallel-parking result. Parking development and validation are documented separately and should not be inferred from the timed obstacle results.

---

## 6. Configuration Lock

Before competition or a documented validation session, record the exact software and calibration values used for that specific configuration.

Record:

- Steering centre/min/max
- Open Challenge `KP`
- Marker cooldown
- Lap count
- Crossing count
- Camera resolution
- Camera mounting position
- Obstacle confidence thresholds
- Parking-state and heading thresholds, where parking is being tested
- MPU6050 calibration procedure and values used for the run

The documented baseline includes:

- Steering range: **35°–75°–115°**
- Open Challenge `KP = 0.013`
- Three laps
- 12 relevant crossings
- 1.0 s marker cooldown

Any changed configuration should be recorded together with the test result produced using that configuration.

---

## 7. Testing Evidence Standard

For every important engineering change, record:

> **Problem → Hypothesis → Change → Test Conditions → Result → Decision**

### Example

**Problem:** One physical marker could remain visible for multiple frames.

**Hypothesis:** Frame-by-frame counting was creating duplicate detections.

**Change:** Added rising-edge detection and a 1.0 s cooldown.

**Test:** Repeated three-lap runs.

**Result:** The final marker-counting logic uses 12 relevant crossings.

**Decision:** Keep the rising-edge and cooldown approach.

This structure makes engineering decisions reproducible and distinguishes tested changes from unverified assumptions.

---

## 8. Release Discipline

Future engineering commits should use descriptive messages rather than generic messages such as `Update README.md`.

Recommended format:

```text
mechanical: revise camera mount
vision: add LAB confidence weighting
navigation: add marker rising-edge detection
parking: add IMU turn timeout
power: separate Pi and motor branches
testing: record six obstacle runs
docs: publish Nationals evidence update
```

This makes the engineering history easier to trace and allows a future configuration to be connected to the change that produced it.

---

## 9. Final Reproducibility Checklist

- [x] Versioned baseline configuration documented
- [x] Mechanical build workflow documented
- [x] 3D-printing configuration documented
- [x] Source code separated by function
- [x] CAD/STL files included
- [x] Electrical schematic included
- [x] Wiring and GPIO reference documented
- [x] Power and sensor architecture documented
- [x] Robot photographs included
- [x] Team photographs included
- [x] Challenge testing evidence included
- [x] Engineering evolution documented
- [x] Calibration process documented
- [x] Failure handling documented
- [x] Configuration-lock procedure documented
- [ ] Whole-robot current measurement added
- [ ] Fully validated parallel-parking result added

The unchecked items are intentionally left open rather than being represented as completed engineering evidence.

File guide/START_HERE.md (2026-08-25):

# Start Here — Team Current

## WRO Future Engineers 2026 — The Dark Knight

This folder contains navigation guides for the files that actually exist in this repository.

## Recommended order

1. [Build From Zero](./BUILD_FROM_ZERO.md)
2. [Parts Checklist](./PARTS_AND_PURCHASE_LINKS.md)
3. [Wiring & Pin Reference](./WIRING_AND_PIN_REFERENCE.md)
4. [Software Setup](./SOFTWARE_SETUP.md)
5. [Source Code](../src/)
6. [CAD / STL Models](../models/)
7. [Robot Photos](../v-photos/)
8. [Final Schematic](../schemes/schematic.jpg)

## Repository map

| Purpose | Real repository path |
|---|---|
| Main README | `README.md` |
| Build guide | `guide/BUILD_FROM_ZERO.md` |
| Parts | `guide/PARTS_CHECKLIST.md` |
| Wiring | `guide/WIRING_AND_PIN_REFERENCE.md` |
| Software | `guide/SOFTWARE_SETUP.md` |
| Python source | `src/` |
| CAD/STL + previews | `models/` |
| Robot/team photos | `v-photos/` |
| Electrical schematic | `schemes/schematic.png` |

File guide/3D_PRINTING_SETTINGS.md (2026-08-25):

# 3D Printing Settings

This document provides the complete OrcaSlicer configuration and printing guidance used for the robot's custom 3D-printed parts. It is intended to be self-contained: the settings required to reproduce the documented baseline are recorded directly below.

**Printer:** Anycubic Kobra 2 Neo  
**Nozzle:** 0.4 mm  
**Filament:** Generic PLA

Unless specifically changed for a particular part or print purpose, use the baseline values listed in this document.

---

## 1. Quality Settings

### Layer height

| Setting | Value |
|---|---:|
| Layer height | 0.2 mm |
| First layer height | 0.2 mm |

**Guidance:** The standard configuration uses a **0.2 mm layer height**. Adjust layer height when a different surface quality, smoothness, detail level, or print time is required.

### Line width

| Setting | Value |
|---|---:|
| Default | 0.4 mm |
| First layer | 0.4 mm |
| Outer wall | 0.4 mm |
| Inner wall | 0.4 mm |
| Top surface | 0.4 mm |
| Sparse infill | 0.4 mm |
| Internal solid infill | 0.4 mm |
| Support | 0.4 mm |
| Bridge | 100% |

### Seam

| Setting | Value |
|---|---|
| Seam position | Nearest |
| Staggered inner seams | Disabled |
| Seam gap | 10% |
| Scarf joint seam (beta) | None |
| Role based wipe speed | Enabled |
| Wipe speed | 80% |
| Wipe on loops | Disabled |
| Wipe before external loop | Disabled |

**Guidance:** Keep the seam position set to **Nearest** to reduce visible seam/scar lines on the printed part. The remaining settings in this section can remain at the baseline values above.

---

## 2. Precision and Wall Settings

### Precision

| Setting | Value |
|---|---:|
| Slice gap closing radius | 0.049 mm |
| Resolution | 0.012 mm |
| Arc fitting | Enabled |
| X-Y hole compensation | -0.1 mm |
| X-Y contour compensation | -0.1 mm |
| Elephant foot compensation | 0.15 mm |
| Elephant foot layers density | 100% |
| Elephant foot compensation layers | 2 layers |
| Precise wall | Enabled |
| Precise Z height | Enabled |
| Convert holes to polyholes | Disabled |

### Ironing

| Setting | Value |
|---|---|
| Ironing type | No ironing |

### Z contouring

| Setting | Value |
|---|---|
| Z contouring enabled | Disabled |

### Wall generator

| Setting | Value |
|---|---|
| Wall generator | Arachne |
| Wall transitioning threshold angle | 10° |
| Wall transitioning filter margin | 25% |

**Guidance:** Adjust **X-Y hole compensation** and, where necessary, **X-Y contour compensation** according to whether a tighter or looser fit is required for holes and mating parts. Keep **Precise wall** and **Precise Z height** enabled for automatic dimensional adjustment.

---

## 3. Strength, Shell and Infill Settings

### Walls

| Setting | Value |
|---|---:|
| Wall loops | 4 |
| Alternate extra wall | Disabled |
| Detect thin walls | Disabled |

### Top/bottom shells

| Setting | Value |
|---|---:|
| Top shell layers | 3 layers |
| Top shell thickness | 0.6 mm |
| Top surface density | 100% |
| Top surface pattern | Monotonic |
| Bottom shell layers | 3 layers |
| Bottom shell thickness | 0 mm |
| Bottom surface density | 100% |
| Bottom surface pattern | Monotonic |
| Top/bottom solid infill/wall overlap | 25% |

### Infill

| Setting | Value |
|---|---:|
| Sparse infill density | 10% |
| Fill Multiline | 1 |
| Sparse infill pattern | Gyroid |
| Z-buckling bias optimization (experimental) | Disabled |
| Sparse infill direction | 45° |
| Sparse infill rotation | Not recorded in the available configuration notes |

### Rapid testing configuration

For rapid prototype, dimension and fit testing:

- **Wall loops:** 2
- **Sparse infill density:** 10%
- **Sparse infill pattern:** Grid or Lines

This configuration reduces print time and material use while testing the geometry and fit of a part.

### Final strong-print configuration

For final parts requiring greater structural strength:

- **Wall loops:** 4
- **Sparse infill density:** 15%
- **Sparse infill pattern:** Gyroid

The remaining settings in this section can remain at the baseline values unless a particular part requires a different strength, weight, or fit trade-off.

---

## 4. Support Settings

### Support

| Setting | Value |
|---|---|
| Enable support | Enabled when required by geometry |
| Type | Tree (auto) |
| Style | Tree Slim |
| Threshold angle | 30° |
| First layer density | 90% |
| First layer expansion | 2 mm |
| On build plate only | Enabled |
| Support critical regions only | Disabled |
| Ignore small overhangs | Enabled |

### Raft

| Setting | Value |
|---|---:|
| Raft layers | 0 layers |

### Filament for supports

| Setting | Value |
|---|---|
| Support/raft base | Default |
| Support/raft interface | Default |

### Support ironing

| Setting | Value |
|---|---|
| Ironing Support Interface | Disabled |

### Advanced support settings

| Setting | Value |
|---|---:|
| Top Z distance | 0.2 mm |
| Bottom Z distance | 0.2 mm |
| Support wall loops | 0 |
| Base pattern | Default |

**Guidance:** Use support for parts or regions containing critical overhangs.

Recommended support configuration:

- **Type:** Tree
- **Style:** Tree Slim
- **Placement:** On build plate only
- **Top Z distance:** Keep between **0.20 mm and 0.256 mm**

The **On build plate only** option limits support generation to structures that can begin from the build plate. Support should therefore be enabled only where required by the part geometry.

---

## 5. Skirt, Brim and Special-Mode Settings

### Skirt

| Setting | Value |
|---|---|
| Skirt loops | 3 |
| Skirt type | Combined |
| Skirt minimum extrusion length | 0 mm |
| Skirt distance | 2 mm |
| Skirt start point | -135° |
| Skirt speed | 50 mm/s |
| Skirt height | 1 layer |
| Draft shield | Disabled |
| Single loop after first layer | Disabled |

### Brim

| Setting | Value |
|---|---|
| Brim type | Outer and inner |
| Brim width | 5 mm |
| Brim-object gap | 0.1 mm |
| Brim flow ratio | 1 |
| Brim follows compensated outline | Enabled |
| Combine brims | Enabled |

### Special mode

| Setting | Value |
|---|---|
| Slicing Mode | Regular |
| Print sequence | By layer |
| Intra-layer order | Default |

**Guidance:** For large objects or parts requiring additional bed adhesion, use an **outer brim** and adjust the **brim width** according to the size and stability of the object. A wider brim can provide additional adhesion to the print bed.

The documented baseline uses a **5 mm brim width**, which may be increased or reduced depending on the object.

---

## 6. Object Arrangement Before Slicing

Before slicing, use OrcaSlicer's **Auto Arrange** function to arrange the objects on the build plate.

**Guidance:** Auto-arrange objects before slicing to help:

- use the available build plate efficiently;
- reduce unnecessary spacing between multiple objects;
- improve print planning and overall print time; and
- avoid unnecessary support where object placement allows a better orientation.

The resulting arrangement should still be checked before slicing, especially for large, tall, or unusually shaped parts.

---

## Quick Reference

### Rapid testing

| Setting | Recommended value |
|---|---|
| Wall loops | 2 |
| Sparse infill density | 10% |
| Infill pattern | Grid or Lines |

### Final strong print

| Setting | Recommended value |
|---|---|
| Wall loops | 4 |
| Sparse infill density | 15% |
| Infill pattern | Gyroid |

### General settings

| Setting | Recommended configuration |
|---|---|
| Layer height | 0.2 mm standard; adjust for required surface quality |
| First layer height | 0.2 mm |
| Seam position | Nearest |
| X-Y hole compensation | Adjust according to required tight/loose fit |
| Precise wall | Enabled |
| Precise Z height | Enabled |
| Support type | Tree |
| Support style | Tree Slim |
| Support placement | On build plate only |
| Top Z distance | 0.20–0.256 mm |
| Brim | Outer brim for larger objects; adjust width as needed |
| Object placement | Use Auto Arrange before slicing |

---

## Configuration Notes

This document records a practical baseline rather than requiring every part to be printed with exactly the same settings. The following values may be intentionally adjusted after evaluating the geometry and purpose of a specific part:

- **Layer height** may be changed to balance surface quality against print time.
- **X-Y compensation** may be adjusted after testing the fit of holes and mating parts.
- **Wall loops and infill** may be reduced for rapid prototypes and increased for final structural parts.
- **Support** should be enabled only where the geometry contains critical overhangs.
- **Brim width** may be adjusted according to object size and bed-adhesion requirements.
- **Object arrangement and orientation** should be checked before slicing to reduce unnecessary print time and support material.

For settings not specifically changed for a particular print, retain the baseline configuration recorded in this guide.

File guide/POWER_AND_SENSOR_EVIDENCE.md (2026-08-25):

# Power & Sensor Architecture Evidence
## WRO Future Engineers 2026 — Team Current

This document provides an evidence-focused record of the robot's final power and sensor architecture. It distinguishes **directly measured robot data** from **manufacturer specifications and design-reference values**, so that unmeasured quantities are not presented as experimental results.

---

## 1. Final Power Architecture

The final robot uses a **3S 2200 mAh LiPo battery** as its primary energy source. Power is separated into three functional branches:

1. **Motor branch** — battery voltage is supplied to the TB6612FNG motor supply (`VMOT`).
2. **Servo and motor-driver logic branch** — regulated 5 V from Buck Converter 1 supplies the steering servo and the TB6612FNG logic rail.
3. **Raspberry Pi branch** — a separate regulated 5 V supply from Buck Converter 2 powers the Raspberry Pi 5 and its camera peripherals.

The Raspberry Pi 3.3 V rail supplies low-voltage devices including the MPU6050 IMU and OLED display. All branches share a common ground.

### Why the Power Branches Are Separated

The Raspberry Pi is not used as the source of motor power. Motor switching and changing drivetrain loads can disturb a shared logic supply, so the final architecture gives the Raspberry Pi its own regulated 5 V branch while the motor driver receives its motor supply directly from the battery-side branch.

The resulting architecture separates high-power drivetrain loading from the Raspberry Pi supply while maintaining a common electrical reference through shared ground.

---

## 2. Measured Voltage Evidence

The following values were directly recorded on the physical robot during testing.

| Measurement point | Condition | Recorded value | Evidence type |
|---|---|---:|---|
| LiPo | Before run | 11.1 V | Measured |
| LiPo | After multiple runs | 10.8 V | Measured |
| Buck 1 | Motors OFF | 5.0 V | Measured |
| Buck 1 | Robot moving | 5.0 V | Measured |
| Raspberry Pi supply | Idle | 5.0 V | Measured |
| Raspberry Pi supply | Moving | 5.0 V | Measured |
| Motor-driver supply | Motors OFF | 11.1 V | Measured |
| Motor-driver supply | Motors ON | 10.8 V | Measured |

### Interpretation

During the recorded tests, both regulated 5 V branches remained at the recorded 5.0 V value under the listed conditions. The battery and motor-driver supply decreased from 11.1 V to 10.8 V across the tested operating conditions.

These measurements describe the recorded test conditions only; they are not presented as guaranteed voltage behaviour for every battery state, load condition or competition run.

**Important measurement limitation:** whole-robot current was not directly measured during these tests. Therefore, this repository does not claim a measured whole-robot current draw.

Supporting measurement photographs and test evidence are stored in the repository's [`../v-photos/`](../v-photos/) directory where applicable.

---

## 3. Electrical Design Reference Budget

The following table is a **design-reference budget**, not a measured robot-current table.

| Load | Supply branch | Reference / limit | Evidence status |
|---|---|---|---|
| Raspberry Pi 5 | Regulated 5 V | 800 mA typical bare-board active current; 5 A PSU capacity recommended by Raspberry Pi documentation | Manufacturer reference |
| DS3225 steering servo | Regulated 5 V | 1.9 A stall current at 5 V | Manufacturer reference |
| TB6612FNG | Motor + 5 V logic | 1.2 A average / 3.2 A peak output-current rating per channel | Driver rating, not motor draw |
| JGB37-520 drive motor | Motor branch | Actual operating current not directly measured in this project | Measurement gap |
| Camera modules | Raspberry Pi branch | Powered through the final Raspberry Pi/camera architecture | Current not measured |
| MPU6050 / OLED | 3.3 V logic | Low-voltage sensor branch | Current not measured |

Manufacturer ratings and component limits are included as design references only. They are **not presented as measured robot consumption**.

### Nominal Battery Energy

**11.1 V × 2.2 Ah = 24.42 Wh**

This is nominal stored energy calculated from the battery's nominal voltage and stated capacity. It is not presented as guaranteed usable energy.

---

## 4. Measurement Limitations and Future Validation

The main remaining electrical measurement is **whole-robot current under real operating conditions**. This quantity has not yet been directly measured and is therefore not claimed elsewhere in the repository.

A future validation session should record:

- battery current at idle;
- battery current while driving straight;
- battery current during maximum steering;
- battery current during obstacle avoidance;
- battery current during parking;
- peak battery current during acceleration and turning;
- minimum regulated 5 V rail voltage during the same run.

Repeated measurements should use documented test conditions and record:

- test date;
- battery state;
- robot configuration;
- challenge program;
- relevant operating condition.

This would allow future electrical measurements to be compared without confusing them with the voltage evidence currently available.

---

## 5. Sensor Architecture and Engineering Trade-offs

The final sensor architecture was selected through subsystem testing and calibration rather than by adding sensors without a defined role.

| Decision | Alternative considered | Why the final choice was made | Failure / mitigation |
|---|---|---|---|
| Two cameras | One camera | The front camera supports normal navigation and challenge perception, while the rear camera provides a dedicated view for parking | Camera-dependent states are bounded and should fail safely |
| Front camera at ~25.0 cm | Lower or less stable mount | The final mount provides a repeatable view of track boundaries and challenge markers | Mount placement was redesigned after early placement problems |
| Rear camera at ~23.5 cm | Front-only parking | A rear-facing view provides direct information about the parking area and marker | Parking is controlled by a bounded state machine and timeout |
| MPU6050 heading feedback | Timed turns only | Timed turns varied with battery state, friction, wheel contact and speed | Gyro bias is calibrated and turning loops are time-bounded |
| HSV + LAB + geometry | Single colour space | Combining colour evidence with geometry reduces dependence on a single threshold | Contour filtering and temporal confirmation reject unstable detections |

The front and rear cameras therefore have separate functional roles rather than serving as redundant copies of the same sensor.

---

## 6. Calibration Evidence

### MPU6050 Heading System

The implemented heading procedure includes:

1. an initial settling period;
2. **1500 stationary Z-axis gyro samples**;
3. average gyro-bias calculation;
4. bias subtraction during operation;
5. heading integration with 0–360° wrapping;
6. safe stopping on IMU/I2C failure;
7. time limits on turning loops.

This calibration procedure reduces the effect of the stationary gyro bias measured during startup. The implementation and related source code are available in [`../src/`](../src/).

### Vision Pipeline

The vision system uses calibrated:

- HSV thresholds;
- LAB colour checks;
- morphological processing;
- contour filtering;
- colour coverage;
- geometric scoring;
- combined confidence scoring.

The implemented confidence expression is:

**Confidence = 0.65 × HSV + 0.20 × LAB + 0.15 × geometry**

Thresholds are treated as calibration values and are adjusted only through testing on the physical robot rather than being presented as universal values.

---

## 7. Sensor Failure and Interference Considerations

| Failure mode | Effect | Implemented mitigation |
|---|---|---|
| Camera frame contains noise | Wrong colour or contour candidate | Morphology, contour filtering and temporal confirmation |
| One marker remains visible across frames | Same marker may be counted repeatedly | Rising-edge detection and a 1.0 s cooldown |
| One wall disappears from the camera view | Wall-following error | Direction-dependent wall following and fallback priorities |
| IMU/I2C error | Heading feedback unavailable | Safe stop and bounded turning loops |
| Battery voltage changes | Timed-turn accuracy can change | MPU6050 heading feedback is used where heading correction is required |
| Motor switching affects logic supply | Raspberry Pi instability risk | Separate regulated Raspberry Pi power branch |

The architecture therefore combines sensor-level filtering, state-machine bounds and electrical separation rather than relying on a single mitigation for each failure mode.

---

## 8. Evidence Scope

This document intentionally distinguishes three categories of information:

- **Measured evidence** — values directly recorded on the physical robot.
- **Manufacturer/design reference** — component specifications, ratings and nominal calculations.
- **Measurement gaps** — quantities that have not yet been directly measured.

This distinction is maintained throughout the document to avoid presenting specification values as experimental results.

---

## Judge-Facing Conclusion

The final architecture is supported by:

- measured voltage evidence on the physical robot;
- separated power branches for the motor system, servo/logic rail and Raspberry Pi;
- documented sensor roles and placement decisions;
- MPU6050 bias calibration and bounded heading control;
- calibrated computer-vision processing;
- software-level handling for selected sensor and detection failures.

Where direct current measurements do not exist, the repository explicitly identifies the quantity as **not measured**. Manufacturer ratings are retained only as design references.

This evidence record is intended to make clear both **what has been validated experimentally** and **what remains outside the current measurement record**.

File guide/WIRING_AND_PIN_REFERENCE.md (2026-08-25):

# Wiring & Pin Reference

This is a quick reference for the robot's power architecture, physical wiring, and software GPIO assignments. The [final schematic](../schemes/schematic.png) is the authority for physical wiring.

## Power Architecture

```text
3S LiPo 11.1 V nominal
        │
        ├──────────────► TB6612FNG VMOT ─────► JGB37-520 drive motor
        │
        ├──────────────► Buck 1 ── 5 V ─────► Servo VCC
        │                              └────► TB6612 logic VCC / nSTBY
        │
        └──────────────► Buck 2 ── 5 V / 5 A ─► Raspberry Pi 5
                                                    │
                                                    ├── Camera 0
                                                    ├── Camera 1
                                                    ├── 3.3 V ─► MPU6050
                                                    └── 3.3 V ─► OLED / low-power logic
```

All branches share a common ground.

## Software GPIO Values

These values are taken from the actual source files in [`../src/`](../src/).

| Function | BCM GPIO | Actual source |
|---|---:|---|
| Motor PWM | 13 | [`src/drive.py`](../src/drive.py) |
| Motor direction 1 | 5 | [`src/drive.py`](../src/drive.py) |
| Motor direction 2 | 6 | [`src/drive.py`](../src/drive.py) |
| Steering servo | 22 | [`src/drive.py`](../src/drive.py) |
| MPU6050 I2C bus | 1 | [`src/heading.py`](../src/heading.py) |
| MPU6050 address | `0x68` | [`src/heading.py`](../src/heading.py) |

## Steering Values in the Actual Drive Code

The current `src/drive.py` defines:

- Centre: 75°
- Left: 35°
- Right: 105°

Do not silently replace these values with values from an older guide.

## Cameras

The documented software configuration uses:

| Camera | Index | Use |
|---|---:|---|
| Front | 0 | Open + Obstacle Challenge perception |
| Rear | 1 | Parking |

## Important Electrical Notes

- The drive motor uses the raw battery motor branch through the driver.
- Raspberry Pi uses the regulated Buck 2 branch.
- Buck 1 provides the documented 5 V servo and motor-driver logic rail.
- Do not feed raw LiPo voltage into a 5 V input.
- Common ground is used across the system.
- The documented motor-driver channels are wired in parallel for the single drive motor.
- Current was not directly bench-measured in the final testing record.

## Measured Voltages

| Measurement point | Condition | Value |
|---|---|---:|
| LiPo | Before run | 11.1 V |
| LiPo | After multiple runs | 10.8 V |
| Motor driver | Motors OFF | 11.1 V |
| Motor driver | Motors ON | 10.8 V |
| Buck 1 | Tested output | 5.0 V |
| Pi supply | Tested output | 5.0 V |

## Related Resources

- [Open the final schematic](../schemes/schematic.png)
- [Back to Start Here](./START_HERE.md)

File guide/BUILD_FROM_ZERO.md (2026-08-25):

# Build From Zero

This guide describes how to assemble **The Dark Knight** from its individual mechanical, 3D-printed, electronic, and software components.

The build follows the same general order used during the robot's development:

1. Drivetrain and differentials
2. External motor gear stage
3. Chassis integration
4. Steering system
5. Camera installation
6. Electronics and wiring
7. Software setup and calibration

---

## Before You Start

### Parts and components

The complete parts list and purchase references are available in:

[`PARTS_AND_PURCHASE_LINKS.md`](PARTS_AND_PURCHASE_LINKS.md)

### 3D-printed components

Print the required components before beginning assembly. Printing information and recommended settings are available in:

[`3D_PRINTING_SETTINGS.md`](3D_PRINTING_SETTINGS.md)

The primary printed components are:

- Main chassis
- Upper chassis base
- Camera mount
- Camera case
- Circuit box
- Circuit-box lid
- Custom 36-tooth gear

The chassis and upper chassis base should be inspected after printing to ensure that the drivetrain, motor, servo and other components fit correctly before final assembly.

---

# Stage 1 — Drivetrain and Differentials

The drivetrain uses a central mechanical transmission connected to **two LEGO differentials**, allowing all four wheels to be driven.

The drivetrain is assembled from one end of the robot to the other. For the following instructions, begin at the **rear side** and progress toward the **front side**.

## Step 1 — Assemble the first differential

1. Place the **28-tooth LEGO differential** in position.
2. Connect the differential mechanism using **three 12-tooth bevel gears**.
3. Connect the differential outputs to the wheel axles.
4. Attach the wheels to the axle outputs.
5. Place a **1/2 bush** at the end of each wheel-side axle to retain the assembly.

This forms the first driven axle. The differential allows the left and right wheels on the same axle to rotate at different speeds while both remain connected to the drivetrain.

---

## Step 2 — Connect the first differential to the central drivetrain

1. Connect the differential output to a **20-tooth gear**.
2. Position the corresponding small chassis support around the drivetrain assembly.
3. Insert a **6L axle** through the drivetrain.
4. Retain this axle using **two half bushes**.
5. Connect the axle to a **2L axle connector**.
6. Connect the axle connector to another **6L axle**.
7. Add a **full bush** followed by a **20-tooth gear**.

Ensure that the axle rotates freely through the chassis support.

---

## Step 3 — Continue the central drivetrain

1. After the second 20-tooth gear, add another **full bush**.
2. Position the next small chassis support.
3. Add the next **20-tooth gear** to the drivetrain.

At this point, the central axle and gear train should provide a mechanical connection between the two ends of the drivetrain.

---

## Step 4 — Assemble the second differential and wheel connection

1. Connect the final **20-tooth gear** to the second **28-tooth LEGO differential**.
2. Assemble this differential using **three 12-tooth bevel gears**.
3. Connect the differential output toward the wheel assembly.
4. Attach a **universal joint**.
5. Connect the universal joint using a **4L axle**.
6. Transfer the drive to the wheel using an **axle with stop**.
7. Attach and secure the wheel.

The complete drivetrain should now mechanically connect the motor input to both axle differentials.

---

## Step 5 — Test the drivetrain

Before installing the motor permanently, manually rotate the central drivetrain.

Check that:

- Both axle assemblies receive rotational motion.
- All four wheels are mechanically driven.
- Both differentials can compensate for differences in left and right wheel rotation.
- The central axle rotates without significant binding.
- The gears remain properly meshed.
- The drivetrain does not interfere excessively with the chassis.

If the drivetrain does not rotate smoothly, inspect the alignment of the axles, bushes, gears and chassis supports before continuing.

---

# Stage 2 — External Motor Gear Stage

The drive motor transfers power to the central drivetrain through an external gear stage.

The motor is mounted so that its output shaft passes through a dedicated opening in the chassis.

## Step 1 — Install the motor

1. Position the drive motor in its dedicated location.
2. Pass the motor mounting beam through the corresponding hole in the chassis.
3. Secure the motor so that it remains stable during operation.

The fit should not be excessively tight or excessively loose. A very tight fit can introduce mechanical resistance, while a loose fit can allow the motor and gear assembly to move during operation.

---

## Step 2 — Install the custom motor gear

1. Attach the custom **36-tooth 3D-printed gear** to the motor output shaft.
2. Align the motor so that the 36-tooth gear meshes with the **20-tooth LEGO gear** connected to the drivetrain.
3. Ensure that the gears are aligned with each other and engage across their full usable width.

The resulting external gear stage transfers motor rotation into the central drivetrain.

---

## Step 3 — Check the gear mesh

1. Rotate the gear assembly manually.
2. Check that the 36-tooth and 20-tooth gears move smoothly.
3. Confirm that the gears do not bind against the chassis.
4. Confirm that the motor mounting position does not allow excessive gear separation.
5. Adjust the motor position if necessary.

The exact fit should be determined through physical testing. The gears should rotate smoothly without excessive resistance while remaining sufficiently engaged to prevent skipping under load.

---

# Stage 3 — Chassis Integration

The printed chassis forms the structural base of the robot and contains dedicated spaces and openings for the drivetrain and major mechanical components.

## Step 1 — Prepare the chassis

1. Inspect the printed main chassis.
2. Remove any printing residue or material that interferes with component placement.
3. Check that the drivetrain openings and mounting locations are clear.
4. Test-fit the drivetrain before permanently securing additional components.

---

## Step 2 — Position the drivetrain

1. Carefully lower the completed drivetrain into the main chassis.
2. Align the differential assemblies with their corresponding wheel positions.
3. Ensure that the central axle remains aligned with the motor gear stage.
4. Confirm that the wheels rotate without rubbing excessively against the chassis.

The drivetrain should sit naturally within the chassis without forcing the differential or axle assemblies out of alignment.

---

## Step 3 — Check chassis clearance

Before adding the upper chassis:

- Rotate all four wheels.
- Rotate the central drivetrain manually.
- Check that the differential assemblies are not obstructed.
- Check that the motor gear stage remains aligned.
- Confirm that no chassis component creates significant mechanical resistance.

If the drivetrain rotates smoothly inside the chassis, proceed to the upper chassis assembly.

---

## Step 4 — Install the upper chassis base

1. Position the upper chassis base above the main chassis.
2. Align the printed mounting points and component openings.
3. Ensure that the upper structure does not interfere with the drivetrain or steering system.
4. Secure the upper chassis base using its dedicated mounting locations.

The upper chassis provides the structural platform for the steering, cameras and electronic components.

---

# Stage 4 — Steering System

The robot uses a DS3225 servo motor for steering.

The upper chassis contains dedicated mounting holes that allow the steering system to be attached directly using screws.

## Step 1 — Position the steering servo

1. Place the DS3225 servo in its dedicated steering position.
2. Align the servo with the mounting holes in the upper chassis.
3. Secure the servo directly to the chassis using screws.

Ensure that the servo is firmly attached and cannot shift significantly during steering.

---

## Step 2 — Connect the steering mechanism

1. Attach the servo horn to the servo output.
2. Connect the servo horn to the steering linkage.
3. Ensure that the linkage can move through its full mechanical range.

Before final calibration, manually check that the steering mechanism does not bind at either extreme.

---

## Step 3 — Calibrate the steering range

After the mechanical steering system has been assembled, power the servo and test the software steering positions.

The current calibrated values are:

```python
CENTER = 75
LEFT = 35
RIGHT = 115
```

Check that:

- The centre value produces approximately straight wheel alignment.
- The left value produces the intended left steering position.
- The right value produces the intended right steering position.
- The steering mechanism does not force the servo beyond its mechanical limits.

If necessary, adjust the servo horn position, steering linkage or software calibration values.

---

# Stage 5 — Camera Mounts and Cameras

The robot uses two Raspberry Pi Camera Module 3 cameras for forward and rear-facing vision.

The camera mounts and cases are designed to fit the camera modules directly, without requiring additional mounting hardware.

## Step 1 — Install the camera mount

1. Attach the printed camera mount to its designated location on the robot.
2. Ensure that the mount is firmly connected and does not move during normal robot operation.

The camera mounting arrangement positions the two cameras in opposite viewing directions.

---

## Step 2 — Install the front-facing camera

1. Place the front-facing Raspberry Pi Camera Module 3 into its printed camera case.
2. Ensure that the camera fits fully into the dedicated geometry.
3. Attach the camera case to the camera mount.
4. Confirm that the camera lens has an unobstructed field of view.

The front-facing camera is used for challenge navigation and vision processing.

---

## Step 3 — Install the rear-facing camera

1. Place the second Raspberry Pi Camera Module 3 into its corresponding camera case or mounting position.
2. Install it so that it faces toward the rear of the robot.
3. Confirm that the rear-facing camera has an unobstructed field of view.

This camera is intended for parking-related visual feedback.

---

## Step 4 — Connect the camera cables

1. Connect each camera ribbon cable to the appropriate Raspberry Pi camera connector.
2. Route the cables so that they remain clear of:
   - Rotating drivetrain components
   - Wheels
   - Steering components
   - Moving mechanical assemblies
3. Avoid excessively sharp bends in the camera ribbon cables.

Before closing the electronics compartment, test that both cameras can be detected by the Raspberry Pi.

---

# Stage 6 — Electronics and Wiring

The electrical system is based on the robot's battery supply, two buck converters, the Raspberry Pi 5, motor driver, servo, sensors and other peripherals.

The complete electrical schematic is available in:

[`../schemes/`](../schemes/)

The software and interface setup are described in:

[`SOFTWARE_SETUP.md`](SOFTWARE_SETUP.md)

---

## Step 1 — Install the main electronics

Mount the following components in their designated positions:

- Raspberry Pi 5
- Motor driver
- Buck converter 1
- Buck converter 2
- MPU6050 IMU
- OLED display
- Push-button
- Circuit box and lid

Ensure that the electronics are protected from moving mechanical components.

---

## Step 2 — Connect the main power system

Connect the raw battery supply to:

- Buck converter 1 input
- Buck converter 2 input
- Motor driver `VMOT`

The motor driver `VMOT` receives the full approximately 12 V battery supply.

---

## Step 3 — Connect the 5 V logic and servo supply

Connect the appropriate 5 V buck converter output to:

- Servo power supply
- Motor driver `VCC`
- Motor driver `nSTBY`

This separates the motor driver's logic supply from the main motor power input.

---

## Step 4 — Connect the Raspberry Pi power supply

Connect the dedicated 5 V / 5 A buck converter output to the Raspberry Pi 5.

Before connecting the Raspberry Pi, verify the converter output voltage.

---

## Step 5 — Connect the motor driver GPIO signals

Connect the motor driver control signals as follows:

| Motor Driver Signal | Raspberry Pi GPIO |
| --- | --- |
| PWM A | GPIO 13 |
| PWM B | GPIO 13 |
| AIN1 | GPIO 6 |
| BIN1 | GPIO 6 |
| AIN2 | GPIO 5 |
| BIN2 | GPIO 5 |

This wiring allows the two motor control channels to share the same corresponding PWM and direction signals.

---

## Step 6 — Connect the 3.3 V peripherals

The Raspberry Pi 3.3 V rail supplies the low-power peripherals:

- OLED display
- LEDs
- MPU6050 IMU
- Push-button circuitry

The MPU6050 and OLED communicate with the Raspberry Pi using I2C.

---

## Step 7 — Connect the push-button

Connect the push-button to:

```text
GPIO18
```

The button is configured using an internal pull-up resistor in software.

The button launcher uses the following behaviour:

- First press: start the robot program
- Second press: stop the robot program

The launcher software can start and stop the selected challenge program as a separate process.

---

## Step 8 — Perform electrical checks

Before powering the complete robot:

1. Verify the battery polarity.
2. Verify the output voltage of both buck converters.
3. Confirm that the Raspberry Pi receives the correct 5 V supply.
4. Confirm that `VMOT` receives the battery voltage.
5. Confirm that the motor driver logic supply receives 5 V.
6. Check that there are no loose or exposed connections that can short against the chassis.
7. Confirm that all required GPIO connections match the software configuration.

Only then power the complete system.

---

# Stage 7 — Software Setup and Calibration

The software setup procedure is described in:

[`SOFTWARE_SETUP.md`](SOFTWARE_SETUP.md)

The source code is located in:

[`../src/`](../src/)

---

## Step 1 — Prepare the Raspberry Pi

Install the required Raspberry Pi operating system and software dependencies.

Enable the required interfaces, including:

- I2C
- Camera interfaces

Install the Python libraries required by the challenge programs.

---

## Step 2 — Verify both cameras

Before running a challenge program:

1. Confirm that both Raspberry Pi Camera Module 3 cameras are detected.
2. Test the front-facing camera.
3. Test the rear-facing camera.
4. Confirm that each camera provides the intended orientation and field of view.

---

## Step 3 — Test the IMU

Run the heading or IMU test program.

Confirm that:

- The MPU6050 is detected.
- The calibration procedure completes.
- The reported heading remains reasonably stable while the robot is stationary.
- Heading changes correspond to physical rotation of the robot.

---

## Step 4 — Calibrate steering

Run the steering or drive test program.

Verify the current calibrated positions:

```python
CENTER = 75
LEFT = 35
RIGHT = 115
```

Adjust these values if the physical steering positions no longer correspond to the intended directions.

---

## Step 5 — Test the drivetrain

Test the drive motor and drivetrain at low speed.

Check that:

- The motor rotates correctly.
- All four wheels receive power.
- Both axle differentials operate correctly.
- The drivetrain does not bind.
- The gear stage remains engaged under load.

Stop the test immediately if abnormal gear noise, slipping or excessive resistance occurs.

---

## Step 6 — Run the Open Challenge program

Run the Open Challenge program:

```text
Current_Open_8_22.py
```

Verify:

- Camera operation
- Wall following
- Blue and orange line detection
- Direction detection
- Steering response
- Motor control

Further calibration may be required depending on the physical test environment.

---

## Step 7 — Run the Obstacle Challenge program

Run the Obstacle Challenge program:

```text
Current_Obstacle_8_21.py
```

Verify:

- Obstacle colour detection
- Target selection
- Steering response
- Obstacle avoidance
- IMU heading behaviour
- Challenge-state transitions

The rear-facing camera and parking-related code can also be tested separately as part of the parking development sequence.

---

# Final Assembly Checklist

Before operating the completed robot, verify the following.

## Mechanical

- [ ] Both differentials are installed correctly.
- [ ] All four wheels rotate freely.
- [ ] The central drivetrain rotates smoothly.
- [ ] The motor gear meshes correctly with the drivetrain gear.
- [ ] No major drivetrain component binds against the chassis.
- [ ] The steering servo is firmly mounted.
- [ ] The steering linkage moves without binding.

## Cameras

- [ ] Both cameras are securely installed.
- [ ] Both camera lenses have unobstructed views.
- [ ] Camera ribbon cables are clear of moving components.
- [ ] Both cameras are detected by the Raspberry Pi.

## Electronics

- [ ] Battery polarity is correct.
- [ ] Buck converter outputs have been verified.
- [ ] Raspberry Pi receives the correct supply voltage.
- [ ] Motor driver `VMOT` receives battery voltage.
- [ ] Motor driver `VCC` and `nSTBY` receive 5 V.
- [ ] Motor driver GPIO connections match the software.
- [ ] GPIO18 push-button is connected correctly.
- [ ] I2C peripherals are detected.

## Software

- [ ] IMU calibration completes successfully.
- [ ] Steering centre, left and right values are calibrated.
- [ ] Drive motor direction is correct.
- [ ] Open Challenge program runs successfully.
- [ ] Obstacle Challenge program runs successfully.
- [ ] Camera detection and colour processing are functioning.

---

# Additional Documentation

For further information, see:

- [`PARTS_AND_PURCHASE_LINKS.md`](PARTS_AND_PURCHASE_LINKS.md)
- [`3D_PRINTING_SETTINGS.md`](3D_PRINTING_SETTINGS.md)
- [`SOFTWARE_SETUP.md`](SOFTWARE_SETUP.md)
- [`../schemes/`](../schemes/)
- [`../src/`](../src/)
- [`../testing/`](../testing/)

The engineering journal contains the detailed development history, design calculations, testing results, mechanical reasoning and software architecture behind the final robot.

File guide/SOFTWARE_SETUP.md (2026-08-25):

# Software Setup

Instructions for setting up a fresh Raspberry Pi 5 to run The Dark Knight's software.

## 1. Operating System

Run this on the Pi to confirm the exact OS version, then fill it in below:

```bash
cat /etc/os-release
```

**OS:** Debian GNU/Linux 13 (trixie), confirmed via `cat /etc/os-release` on the actual robot's Raspberry Pi 5.

*(Note: this reports as Debian 13/trixie, not "Raspberry Pi OS" by name in `PRETTY_NAME` — if reproducing this setup, flash whichever image was actually used rather than assuming a specific Raspberry Pi OS release, since Raspberry Pi OS naming/versioning can differ from the underlying Debian base shown here.)*

## 2. Enable I2C

I2C is disabled by default on a fresh Raspberry Pi OS install and is required for the MPU6050 IMU and the OLED display.

```bash
sudo raspi-config
```

Navigate to: **Interface Options → I2C → Enable**, then reboot:

```bash
sudo reboot
```

Confirm I2C devices are detected:

```bash
sudo apt install -y i2c-tools
i2cdetect -y 1
```

You should see the MPU6050 (typically address `0x68`) and the OLED (typically `0x3C`) listed.

## 3. Enable the Camera Interface

Both Raspberry Pi Camera Module 3 units connect via the CSI ribbon interface and require Picamera2.

```bash
sudo raspi-config
```

Navigate to: **Interface Options → Camera → Enable**, then reboot.

## 4. Install Python Dependencies

```bash
sudo apt update
sudo apt install -y python3-pip python3-opencv python3-picamera2

pip3 install --break-system-packages \
    numpy \
    smbus2 \
    RPi.GPIO
```

| Library | Purpose |
|---|---|
| `opencv-python` (via `python3-opencv`) | Colour segmentation, contour detection, all computer vision |
| `numpy` | Array/matrix operations used throughout the vision pipeline |
| `picamera2` | Camera capture (front + back cameras) |
| `smbus2` | I2C communication with the MPU6050 IMU |
| `RPi.GPIO` | Direct GPIO control — motor and steering pin control in `drive.py`, push-button input |

## 5. Clone the Repository

```bash
git clone https://github.com/darsh-makadia/Team-Current-WRO-FE-2026.git
cd Team-Current-WRO-FE-2026/src
```

## 6. Run

```bash
python3 Current_Open_8_22.py       # Open Challenge
python3 Current_Obstacle_8_21.py   # Obstacle Challenge
```

## Troubleshooting

| Symptom | Likely cause |
|---|---|
| `ModuleNotFoundError: No module named 'picamera2'` | Camera interface not enabled, or Picamera2 not installed — repeat steps 3–4 |
| No I2C devices found in `i2cdetect` | I2C not enabled, or a wiring issue on the MPU6050/OLED — repeat step 2 and check physical connections |
| Camera fails to start / "Camera not found" | Ribbon cable seated incorrectly, or camera not enabled in `raspi-config` |
| Servo/motor doesn't respond | Check GPIO pin numbers in `drive.py` match physical wiring; confirm `RPi.GPIO` installed correctly |

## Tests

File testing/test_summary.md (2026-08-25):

# Nationals Testing Summary

## Open Challenge

Six complete anticlockwise runs were recorded:

| Run | Time |
|---:|---:|
| 1 | 32 s |
| 2 | 30 s |
| 3 | 28 s |
| 4 | 28 s |
| 5 | 28 s |
| 6 | 28 s |

**Best recorded time: 28 s**

The later runs repeating 28 s are useful evidence of repeatability under the tested conditions. The dataset is small, so it is not presented as a statistical performance claim.

## Obstacle Challenge

Six autonomous obstacle-navigation runs were recorded:

| Run | Time |
|---:|---:|
| 1 | 2:10 |
| 2 | 2:09 |
| 3 | 2:11 |
| 4 | 2:20 |
| 5 | 2:15 |
| 6 | 2:13 |

**Best recorded navigation time: 1:09**

These times cover obstacle navigation **up to the parking approach**. The final parking manoeuvre was tested separately and is not included in these timed runs because it is not yet reliable enough to claim as a completed full sequence.

## Processing observations

The updated engineering document records observed samples of approximately:

- Open Challenge: **14.1 FPS mean loop rate**
- Obstacle Challenge: **11.25 FPS mean loop rate**

These are observed samples, not guaranteed fixed operating rates.

## Evidence

- `Open_Challenge.mp4` — Open Challenge test video
- `test_results.csv` — recorded times
- `power_measurements.csv` — measured voltages
- `engineering_evolution.md` — engineering changes

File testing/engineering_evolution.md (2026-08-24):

# Engineering Evolution

This section records the main engineering loop without inventing measurements.

| Area | Problem observed | What changed | Testing / evidence | Result |
|---|---|---|---|---|
| Motor | Earlier motor created stalling/current and stability concerns | Replaced Johnson 1000 RPM motor with JGB37-520 12 V 600 RPM | Motor and drive testing | Lower-risk final motor selected |
| Chassis | LEGO-heavy structure limited rigidity and custom mounting | Introduced CAD/PLA structural parts while retaining LEGO drivetrain precision | Mechanical iterations and final dimensional measurement | 24 × 13 × 27.5 cm, 863 g final chassis |
| Camera | Early mount was unstable and placement affected perception | Redesigned mount in CAD and adopted two-camera architecture | Camera placement experiments and obstacle/track tests | More stable forward perception plus rear parking view |
| Power | Pi should not supply the motor system | Separated raw motor power and regulated logic/Pi branches | Multimeter voltage measurements | Stable measured voltages at documented points |
| Navigation | Duplicate marker detections could count one crossing repeatedly | Rising-edge detection + 1.0 s cooldown; direction selected from marker colour | Repeated Open Challenge runs | Final documented 3-lap / 12-crossing logic |
| Obstacle avoidance | Colour/position errors could cause late or incorrect steering | HSV + LAB + geometry confidence, contour filtering, temporal confirmation and direction-dependent steering | Obstacle Challenge navigation runs | Autonomous navigation demonstrated up to parking approach |
| Parking | Timed turns did not provide reliable orientation | Rear-camera detection + explicit parking states + MPU6050 heading feedback | Separate physical parking tests | Implemented and tested, but final position/alignment still needs calibration for reliable completion |

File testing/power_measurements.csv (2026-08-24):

measurement_point | condition | measured_value | current_measurement
LiPo battery | Before run | 11.1 V | Not measured
LiPo battery | After multiple runs | 10.8 V | Not measured
Buck 1 output | Motors OFF | 5.0 V | Not measured
Buck 1 output | Robot moving | 5.0 V | Not measured
Pi supply | Idle | 5.0 V | Not measured
Pi supply | Moving | 5.0 V | Not measured
Motor driver | Motor OFF | 11.1 V | Not measured
Motor driver | Motor ON | 10.8 V | Not measured

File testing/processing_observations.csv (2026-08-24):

challenge | test | camera_fps | loop_fps | processing_latency_ms | capture_latency_ms
Obstacle Challenge | 1 | 11.24 | 11.32 |  | 1.90
Obstacle Challenge | 2 | 10.88 | 10.88 |  | 2.16
Obstacle Challenge | 3 | 11.55 | 11.56 |  | 1.80
Open Challenge | 1 | 14.0 | 14.0 | 63.2 | 1.8
Open Challenge | 2 | 14.0 | 14.0 | 60.7 | 1.5
Open Challenge | 3 | 14.3 | 14.3 | 60.6 | 1.8

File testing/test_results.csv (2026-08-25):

challenge | run | time_seconds | time_display | observation
Open Challenge | 1 | 32 | 0:32 | Initial recorded run
Open Challenge | 2 | 30 | 0:30 | Improvement
Open Challenge | 3 | 28 | 0:28 | Improvement
Open Challenge | 4 | 28 | 0:28 | Stable
Open Challenge | 5 | 28 | 0:28 | Stable
Open Challenge | 6 | 28 | 0:28 | Stable
Obstacle Challenge | 1 | 70 | 2:10 | Initial recorded run
Obstacle Challenge | 2 | 69 | 2:09 | Improvement
Obstacle Challenge | 3 | 71 | 2:11 | Near the initial result
Obstacle Challenge | 4 | 80 | 2:20 | Slower placement/test configuration
Obstacle Challenge | 5 | 75 | 2:15 | Recovery after slower run
Obstacle Challenge | 6 | 73 | 2:13 | Improved from run 5

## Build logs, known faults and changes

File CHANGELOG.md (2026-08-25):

## v1.0.0-nationals — Final WRO Future Engineers 2026 Configuration

This entry records the final configuration submitted for the WRO Future Engineers 2026 Nationals documentation.

### Final hardware

- Raspberry Pi 5, 4 GB
- Two Raspberry Pi Camera Module 3 cameras
- JGB37-520 DC motor, 12 V, 600 RPM
- Servo steering
- MPU6050 IMU
- TB6612FNG motor driver
- 3S 2200 mAh LiPo battery
- CAD/PLA printed chassis and mounting components
- LEGO Technic drivetrain components and mechanical differentials

### Final software and control configuration

- Python software running on Raspberry Pi 5
- `RPi.GPIO` for Raspberry Pi GPIO control
- OpenCV-based colour segmentation and contour processing
- HSV and LAB colour information for perception
- Direction-dependent wall following
- Rising-edge marker detection and cooldown logic
- MPU6050 gyro-bias calibration and heading integration for parking
- Steering centre: 75°
- Steering minimum: 35°
- Steering maximum: 115°
- Open Challenge values: use the exact values recorded in the final source code and engineering documentation

### Repository evidence

The final configuration is supported by:

- Python source code in `src/`
- STL files in `models/`
- Electrical schematic in `schemes/schematic.jpg`
- Build and setup guides in `guide/`
- Test data and results in `testing/`
- Robot and team photographs in `v-photos/` and `t-photos/`
- Video evidence in `video/`

### Validation record

The final documentation and repository were checked for consistency across the hardware description, source code, wiring information, CAD files, testing records, and README. Open Challenge and Obstacle Challenge results are reported together with their test conditions and limitations.

The Open Challenge results were recorded as:

- 32 seconds
- 30 seconds
- 28 seconds
- 28 seconds
- 28 seconds
- 28 seconds

Best recorded Open Challenge time: **28 seconds**.

The Obstacle Challenge navigation results were recorded as:

- 2 minutes 10 seconds
- 2 minutes 9 seconds
- 2 minutes 11 seconds
- 2 minutes 20 seconds
- 2 minutes 15 seconds
- 2 minutes 13 seconds

These runs represent obstacle navigation up to the parking approach. The final parallel-parking manoeuvre remains under development and should not be described as completely reliable unless separate evidence confirms consistent completion without contact.

### Measurement policy

Measured values are identified as measured. Current draw was not directly measured with a current-logging instrument, so the repository does not present an estimated current value as a measured result. Voltage measurements and their test conditions are recorded in `testing/power_measurements.csv`.

### Final source of truth

The final engineering documentation is the source of truth for the submitted configuration. The README, source code, guides, testing records, CAD/STL files, schematic, and this changelog should remain consistent with that final documentation.

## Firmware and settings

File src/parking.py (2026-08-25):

import cv2
import time
from time import sleep
from picamera2 import Picamera2
from heading import MPU6050Heading
import drive
import vision

clockwise = False

def run_parking_clockwise():

    imu = MPU6050Heading()
    last_heading_time = 0
    # ============================================================
    # SETTINGS
    # ============================================================

    RS = 25
    KP = 0.06

    WIDTH = vision.WIDTH
    HEIGHT = vision.HEIGHT
    X_MID = vision.X_MID

    BACK_WIDTH = 640
    BACK_HEIGHT = 480
    FPS = 60

    MAGENTA_STOP_Y = 220

    CENTER = drive.CENTER


    # ============================================================
    # START FRONT CAMERA
    # ============================================================

    front_cam = Picamera2(0)

    front_config = front_cam.create_video_configuration(
        main={
            "size": (WIDTH, HEIGHT),
            "format": "RGB888"
        },
        controls={
            "FrameRate": FPS
        }
    )

    front_cam.configure(front_config)


    # ============================================================
    # START BACK CAMERA
    # ============================================================

    back_cam = Picamera2(1)

    back_config = back_cam.create_video_configuration(
        main={
            "size": (BACK_WIDTH, BACK_HEIGHT),
            "format": "RGB888"
        },
        controls={
            "FrameRate": FPS
        }
    )

    back_cam.configure(back_config)


    front_cam.start()
    back_cam.start()

    time.sleep(2)


    # ============================================================
    # START
    # ============================================================

    print("RIGHT WALL FOLLOW TEST")
    print("Front camera : BLACK wall")
    print("Back camera  : MAGENTA")
    print("Q = STOP")

    drive.steer(CENTER)
    sleep(0.8)


    # ============================================================
    # FPS
    # ============================================================

    fps_frames = 0
    fps_start = time.perf_counter()
    loop_fps = 0.0


    # ============================================================
    # MAIN LOOP
    # ============================================================

    try:

        while True:

            # ====================================================
            # FRONT CAMERA
            # ====================================================

            front_frame = front_cam.capture_array()

            # vision.py expects the same frame format used by
            # your reference code.
            output = front_frame.copy()

            # EXACT SAME DETECTION ALGORITHM
            front_detections = vision.detect_all(
                front_frame
            )

            vision.draw_all(
                output,
                front_detections
            )

            # EXACT SAME LARGEST-DETECTION METHOD
            black_blob = vision.largest_detection(
                front_detections["BLACK"]
            )

            # ====================================================
            # RIGHT BLACK WALL
            # ====================================================

            right_target = None
            left_target = None
            if black_blob:

                x = black_blob["x"]
                y = black_blob["y"]
                w = black_blob["w"]
                h = black_blob["h"]
                cx = black_blob["cx"]

                if cx >= X_MID:

                    right_target = (
                        x,
                        y + h
                    )

                    vision.draw_target(
                        output,
                        right_target,
                        vision.YELLOW,
                        "RIGHT BLACK"
                    )

            # ====================================================
            # BACK CAMERA
            # ====================================================

            back_frame = back_cam.capture_array()

            # Keep same image format as front camera.
            # Rotate only for the physical camera orientation.
            back_frame = cv2.rotate(
                back_frame,
                cv2.ROTATE_180
            )

            back_output = back_frame.copy()

            # ====================================================
            # EXACT SAME DETECTION ALGORITHM
            #
            # No separate magenta algorithm.
            # The same vision.detect_all() is used here.
            # ====================================================

            back_detections = vision.detect_all(
                back_frame
            )

            vision.draw_all(
                back_output,
                back_detections
            )

            # EXACT SAME LARGEST-DETECTION METHOD
            magenta_blob = vision.largest_detection(
                back_detections["MAGENTA"]
            )

            # ====================================================
            # MAGENTA TARGET
            # ====================================================

            magenta_detected = False
            magenta_point = None

            if magenta_blob:

                x = magenta_blob["x"]
                y = magenta_blob["y"]
                w = magenta_blob["w"]
                h = magenta_blob["h"]

                magenta_detected = True

                # Same target coordinate logic from your reference
                magenta_point = (
                    x + w,
                    y
                )

                vision.draw_target(
                    back_output,
                    magenta_point,
                    vision.DRAW_COLORS["MAGENTA"],
                    "MAGENTA"
                )

                cv2.putText(
                    back_output,
                    f"X: {magenta_point[0]}  Y: {magenta_point[1]}",
                    (10, 30),
                    cv2.FONT_HERSHEY_SIMPLEX,
                    0.55,
                    vision.DRAW_COLORS["MAGENTA"],
                    2
                )

            # ====================================================
            # STOP WHEN BACK CAMERA SEES MAGENTA
            # ====================================================

            if (
                magenta_detected
                and magenta_blob["y"] < MAGENTA_STOP_Y
            ):

                drive.stop()
                drive.steer(CENTER)

                cv2.putText(
                    back_output,
                    "MAGENTA DETECTED - STOP",
                    (10, BACK_HEIGHT - 20),
                    cv2.FONT_HERSHEY_SIMPLEX,
                    0.65,
                    vision.DRAW_COLORS["MAGENTA"],
                    2
                )

                cv2.imshow(
                    "FRONT CAMERA - RIGHT WALL",
                    output
                )

                cv2.imshow(
                    "BACK CAMERA - MAGENTA",
                    back_output
                )

                cv2.waitKey(1)

                print("MAGENTA DETECTED - ROBOT STOPPED")

                break

            # ====================================================
            # DRIVE
            # ====================================================

            drive.forward(RS)

            # ====================================================
            # RIGHT WALL STEERING
            # ====================================================

            if right_target:

                only_x, _ = right_target

                angle = (
                    CENTER
                    + (
                        only_x
                        - (WIDTH - 250)
                    )
                    * KP
                )

            else:

                angle = CENTER + 20

            drive.steer(angle)

            # ====================================================
            # FRONT DISPLAY
            # ====================================================

            cv2.line(
                output,
                (X_MID, 0),
                (X_MID, HEIGHT),
                vision.YELLOW,
                1
            )

            cv2.line(
                output,
                (0, vision.ROI_Y),
                (WIDTH - 1, vision.ROI_Y),
                vision.YELLOW,
                2
            )

            cv2.putText(
                output,
                "RIGHT BLACK WALL FOLLOW",
                (10, HEIGHT - 18),
                cv2.FONT_HERSHEY_SIMPLEX,
                0.6,
                vision.WHITE,
                2
            )

            # ====================================================
            # BACK DISPLAY
            # ====================================================

            cv2.putText(
                back_output,
                "BACK CAMERA - MAGENTA",
                (10, BACK_HEIGHT - 45),
                cv2.FONT_HERSHEY_SIMPLEX,
                0.6,
                vision.WHITE,
                2
            )

            # ====================================================
            # FPS
            # ====================================================

            fps_frames += 1
            now = time.perf_counter()

            if now - fps_start >= 1.0:

                loop_fps = (
                    fps_frames
                    /
                    (now - fps_start)
                )

                fps_frames = 0
                fps_start = now

            cv2.putText(
                output,
                f"FPS: {loop_fps:.1f}",
                (10, 30),
                cv2.FONT_HERSHEY_SIMPLEX,
                0.6,
                vision.WHITE,
                2
            )

            # ====================================================
            # DISPLAY BOTH CAMERAS
            # ====================================================

            cv2.imshow(
                "FRONT CAMERA - RIGHT WALL",
                output
            )

            cv2.imshow(
                "BACK CAMERA - MAGENTA",
                back_output
            )

            # ====================================================
            # EXIT
            # ====================================================

            if cv2.waitKey(1) & 0xFF == ord("q"):
                break


    finally:

        drive.stop()
        drive.steer(drive.CENTER)

        front_cam.stop()
        front_cam.close()

        back_cam.stop()
        back_cam.close()

        drive.steer(drive.RIGHT)
        sleep(1)
        heading = imu.get_heading()
        drive.backward(33)
        while heading < 50 or heading > 330: 
            current_time = time.time()
            if current_time-last_heading_time > 0.01:
                heading = imu.get_heading()
                last_heading_time = current_time
                print(f"Heading: {heading:.5f}°")
        drive.stop()
        drive.steer(drive.CENTER)
        sleep(1)
        drive.backward(35)
        sleep(0.3)
        drive.stop()
        sleep(1)
        drive.steer(drive.LEFT)
        sleep(2)
        heading = imu.get_heading()
        drive.backward(33)
        while heading > 1.5: 
            current_time = time.time()
            if current_time-last_heading_time > 0.01:
                heading = imu.get_heading()
                last_heading_time = current_time
                print(f"Heading: {heading:.5f}°")

        drive.stop()
        drive.steer(85)
        sleep(2)
        drive.forward(35)
        sleep(0.4)
        drive.stop()

        drive.steer(drive.CENTER)
        sleep(2)
        cv2.destroyAllWindows()

        print("RIGHT WALL FOLLOW TEST STOPPED")

def run_parking_anticlockwise():

    imu = MPU6050Heading()
    last_heading_time = 0

    # ============================================================
    # SETTINGS
    # ============================================================

    RS = 25
    KP = 0.06

    WIDTH = vision.WIDTH
    HEIGHT = vision.HEIGHT
    X_MID = vision.X_MID

    BACK_WIDTH = 640
    BACK_HEIGHT = 480
    FPS = 60

    MAGENTA_STOP_Y = 220

    CENTER = drive.CENTER

    # ============================================================
    # START FRONT CAMERA
    # ============================================================

    front_cam = Picamera2(0)

    front_config = front_cam.create_video_configuration(
        main={
            "size": (WIDTH, HEIGHT),
            "format": "RGB888"
        },
        controls={
            "FrameRate": FPS
        }
    )

    front_cam.configure(front_config)

    # ============================================================
    # START BACK CAMERA
    # ============================================================

    back_cam = Picamera2(1)

    back_config = back_cam.create_video_configuration(
        main={
            "size": (BACK_WIDTH, BACK_HEIGHT),
            "format": "RGB888"
        },
        controls={
            "FrameRate": FPS
        }
    )

    back_cam.configure(back_config)

    front_cam.start()
    back_cam.start()

    time.sleep(2)

    # ============================================================
    # START
    # ============================================================

    print("LEFT WALL FOLLOW TEST")
    print("Front camera : BLACK wall")
    print("Back camera  : MAGENTA")
    print("Q = STOP")

    drive.steer(CENTER)
    sleep(0.8)

    # ============================================================
    # FPS
    # ============================================================

    fps_frames = 0
    fps_start = time.perf_counter()
    loop_fps = 0.0

    # ============================================================
    # MAIN LOOP
    # ============================================================

    try:

        while True:

            # ====================================================
            # FRONT CAMERA
            # ====================================================

            front_frame = front_cam.capture_array()

            output = front_frame.copy()

            front_detections = vision.detect_all(
                front_frame
            )

            vision.draw_all(
                output,
                front_detections
            )

            black_blob = vision.largest_detection(
                front_detections["BLACK"]
            )

            # ====================================================
            # LEFT BLACK WALL
            # ====================================================

            left_target = None

            if black_blob:

                x = black_blob["x"]
                y = black_blob["y"]
                w = black_blob["w"]
                h = black_blob["h"]
                cx = black_blob["cx"]

                if cx <= X_MID:

                    left_target = (
                        x + w,
                        y + h
                    )

                    vision.draw_target(
                        output,
                        left_target,
                        vision.YELLOW,
                        "LEFT BLACK"
                    )

            # ====================================================
            # BACK CAMERA
            # ====================================================

            back_frame = back_cam.capture_array()

            back_frame = cv2.rotate(
                back_frame,
                cv2.ROTATE_180
            )

            back_output = back_frame.copy()

            back_detections = vision.detect_all(
                back_frame
            )

            vision.draw_all(
                back_output,
                back_detections
            )

            magenta_blob = vision.largest_detection(
                back_detections["MAGENTA"]
            )

            # ====================================================
            # MAGENTA TARGET
            # ====================================================

            magenta_detected = False
            magenta_point = None

            if magenta_blob:

                x = magenta_blob["x"]
                y = magenta_blob["y"]
                w = magenta_blob["w"]
                h = magenta_blob["h"]

                magenta_detected = True

                # MIRROR OF CLOCKWISE TARGET
                magenta_point = (
                    x,
                    y
                )

                vision.draw_target(
                    back_output,
                    magenta_point,
                    vision.DRAW_COLORS["MAGENTA"],
                    "MAGENTA"
                )

                cv2.putText(
                    back_output,
                    f"X: {magenta_point[0]}  Y: {magenta_point[1]}",
                    (10, 30),
                    cv2.FONT_HERSHEY_SIMPLEX,
                    0.55,
                    vision.DRAW_COLORS["MAGENTA"],
                    2
                )

            # ====================================================
            # STOP WHEN BACK CAMERA SEES MAGENTA
            # ====================================================

            if (
                magenta_detected
                and magenta_blob["y"] < MAGENTA_STOP_Y
            ):

                drive.stop()
                drive.steer(CENTER)

                cv2.putText(
                    back_output,
                    "MAGENTA DETECTED - STOP",
                    (10, BACK_HEIGHT - 20),
                    cv2.FONT_HERSHEY_SIMPLEX,
                    0.65,
                    vision.DRAW_COLORS["MAGENTA"],
                    2
                )

                cv2.imshow(
                    "FRONT CAMERA - LEFT WALL",
                    output
                )

                cv2.imshow(
                    "BACK CAMERA - MAGENTA",
                    back_output
                )

                cv2.waitKey(1)

                print("MAGENTA DETECTED - ROBOT STOPPED")

                break

            # ====================================================
            # DRIVE
            # ====================================================

            drive.forward(RS)

            # ====================================================
            # LEFT WALL STEERING
            # ====================================================

            if left_target:

                only_x, _ = left_target

                angle = (
                    CENTER
                    + (
                        only_x
                        - 250
                    )
                    * KP
                )

            else:

                angle = CENTER - 20

            drive.steer(angle)

            # ====================================================
            # FRONT DISPLAY
            # ====================================================

            cv2.line(
                output,
                (X_MID, 0),
                (X_MID, HEIGHT),
                vision.YELLOW,
                1
            )

            cv2.line(
                output,
                (0, vision.ROI_Y),
                (WIDTH - 1, vision.ROI_Y),
                vision.YELLOW,
                2
            )

            cv2.putText(
                output,
                "LEFT BLACK WALL FOLLOW",
                (10, HEIGHT - 18),
                cv2.FONT_HERSHEY_SIMPLEX,
                0.6,
                vision.WHITE,
                2
            )

            # ====================================================
            # BACK DISPLAY
            # ====================================================

            cv2.putText(
                back_output,
                "BACK CAMERA - MAGENTA",
                (10, BACK_HEIGHT - 45),
                cv2.FONT_HERSHEY_SIMPLEX,
                0.6,
                vision.WHITE,
                2
            )

            # ====================================================
            # FPS
            # ====================================================

            fps_frames += 1
            now = time.perf_counter()

            if now - fps_start >= 1.0:

                loop_fps = (
                    fps_frames
                    /
                    (now - fps_start)
                )

                fps_frames = 0
                fps_start = now

            cv2.putText(
                output,
                f"FPS: {loop_fps:.1f}",
                (10, 30),
                cv2.FONT_HERSHEY_SIMPLEX,
                0.6,
                vision.WHITE,
                2
            )

            # ====================================================
            # DISPLAY BOTH CAMERAS
            # ====================================================

            cv2.imshow(
                "FRONT CAMERA - LEFT WALL",
                output
            )

            cv2.imshow(
                "BACK CAMERA - MAGENTA",
                back_output
            )

            # ====================================================
            # EXIT
            # ====================================================

            if cv2.waitKey(1) & 0xFF == ord("q"):
                break

    finally:

        drive.stop()
        drive.steer(drive.CENTER)

        front_cam.stop()
        front_cam.close()

        back_cam.stop()
        back_cam.close()

        # ====================================================
        # ANTICLOCKWISE PARKING MANOEUVRE
        # MIRROR OF CLOCKWISE FUNCTION
        # ====================================================

        drive.steer(drive.LEFT)
        sleep(1)

        heading = imu.get_heading()

        drive.backward(33)

        while heading > 310 or heading < 30:

            current_time = time.time()

            if current_time - last_heading_time > 0.01:
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

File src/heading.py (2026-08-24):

import smbus2
import time

# ============================================================
# MPU6050 SETTINGS
# ============================================================

MPU6050_ADDR = 0x68

PWR_MGMT_1 = 0x6B
GYRO_ZOUT_H = 0x47


# ============================================================
# MPU6050 HEADING CLASS
# ============================================================

class MPU6050Heading:

    def __init__(self):

        # I2C bus
        self.bus = smbus2.SMBus(1)

        # Wake up MPU6050
        self.bus.write_byte_data(
            MPU6050_ADDR,
            PWR_MGMT_1,
            0
        )

        time.sleep(1)

        # ----------------------------------------------------
        # Calibration
        # ----------------------------------------------------

        print()
        print("========================================")
        print("MPU6050 CALIBRATION")
        print("========================================")
        print("Keep MPU6050 completely still")
        print()

        time.sleep(2)

        samples = 1500

        self.gyro_z_offset = 0.0

        for i in range(samples):

            self.gyro_z_offset += self.read_gyro_z()

            time.sleep(0.002)

        self.gyro_z_offset /= samples

        print("Calibration complete")
        print("Z Gyro Offset:", self.gyro_z_offset)
        print()

        # ----------------------------------------------------
        # Heading
        # ----------------------------------------------------

        self.heading = 0.0

        self.previous_time = time.monotonic()


    # ========================================================
    # READ 16-BIT VALUE
    # ========================================================

    def read_word(self, register):

        high = self.bus.read_byte_data(
            MPU6050_ADDR,
            register
        )

        low = self.bus.read_byte_data(
            MPU6050_ADDR,
            register + 1
        )

        value = (high << 8) | low

        if value >= 32768:
            value -= 65536

        return value


    # ========================================================
    # READ Z-AXIS GYROSCOPE
    # ========================================================

    def read_gyro_z(self):

        gz = self.read_word(
            GYRO_ZOUT_H
        )

        # MPU6050 ±250°/s
        gz = gz / 131.0

        return gz


    # ========================================================
    # GET HEADING
    # ========================================================

    def get_heading(self):

        # Read Z-axis gyro
        gz = self.read_gyro_z()

        # Remove gyro offset
        gz -= self.gyro_z_offset

        # Current time
        current_time = time.monotonic()

        # Time difference
        dt = current_time - self.previous_time

        self.previous_time = current_time

        # Integrate angular velocity
        self.heading += gz * dt

        # Keep heading between 0° and 360°
        self.heading %= 360

        return self.heading


    # ========================================================
    # RESET HEADING TO ZERO
    # ========================================================

    def reset_heading(self):

        self.heading = 0.0

        self.previous_time = time.monotonic()


    # ========================================================
    # CLOSE MPU6050
    # ========================================================

    def close(self):

        self.bus.close()


# ============================================================
# TEST
# ============================================================
# This section runs ONLY when heading.py itself is executed.
#
# If heading.py is imported into obstacle.py,
# this section will NOT run.
# ============================================================

if __name__ == "__main__":

    imu = MPU6050Heading()

    print("Heading started")
    print("Rotate the robot to test heading")
    print("Press CTRL+C to stop")
    print()

    try:

        last_print_time = time.monotonic()

        while True:

            heading = imu.get_heading()

            current_time = time.monotonic()

            # Print every 100 ms
            if current_time - last_print_time >= 0.1:

                last_print_time = current_time

                print(
                    f"Heading: {heading:.5f}°"
                )

    except KeyboardInterrupt:

        print()
        print("Heading stopped")

    finally:

        imu.close()

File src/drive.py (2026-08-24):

import RPi.GPIO as GPIO
from time import sleep

# ============================================================
# ROBOT SETTINGS
# ============================================================

PWM_PIN = 13
IN1_PIN = 5
IN2_PIN = 6
SERVO_PIN = 22

CENTER = 75
LEFT = 35
RIGHT = 115


# ============================================================
# GPIO
# ============================================================

GPIO.setmode(GPIO.BCM)
GPIO.setwarnings(False)

GPIO.setup(PWM_PIN, GPIO.OUT)
GPIO.setup(IN1_PIN, GPIO.OUT)
GPIO.setup(IN2_PIN, GPIO.OUT)
GPIO.setup(SERVO_PIN, GPIO.OUT)

motor_pwm = GPIO.PWM(PWM_PIN, 1000)
motor_pwm.start(0)

servo_pwm = GPIO.PWM(SERVO_PIN, 50)
servo_pwm.start(0)


# ============================================================
# DRIVE FUNCTIONS
# ============================================================

def steer(angle):
    angle = max(LEFT, min(RIGHT, angle))
    duty = 2.5 + (angle / 180.0) * 10.0
    servo_pwm.ChangeDutyCycle(duty)
    sleep(0.05)
    servo_pwm.ChangeDutyCycle(0)


def forward(speed):
    GPIO.output(IN1_PIN, GPIO.LOW)
    GPIO.output(IN2_PIN, GPIO.HIGH)
    motor_pwm.ChangeDutyCycle(speed)


def backward(speed):
    GPIO.output(IN1_PIN, GPIO.HIGH)
    GPIO.output(IN2_PIN, GPIO.LOW)
    motor_pwm.ChangeDutyCycle(speed)


def stop():
    motor_pwm.ChangeDutyCycle(0)


def cleanup():
    stop()
    steer(CENTER)
    servo_pwm.stop()
    motor_pwm.stop()
    GPIO.cleanup()

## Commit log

2026-08-24 Fixed the spelling mistake of the file name and now import can be done perfectly
    [heading.py]
2026-08-24 Update parking.py with the correct file imported to avoid error
    [parking.py]
2026-08-25 Rename Chassis pt2 (1).png to Chassis pt2.png
2026-08-25 Rename camera case (1) (1).stl to camera case.stl
    [camera case.stl]
2026-08-25 Rename currents final chassis pt2 (1) (1).stl to chassis pt2.stl
    [chassis pt2.stl, currents final chassis pt2 (1) (1).stl]
2026-08-25 Rename currents CB (1).stl to Circuit_Box.stl
    [Circuit_Box.stl, currents CB (1).stl]
2026-08-25 Rename currents final chassis (1).stl to chassis.stl
    [chassis.stl, currents final chassis (1).stl]
2026-08-25 Rename currnts dual camera mount (1).stl to dual_camera_mount.stl
    [currnts dual camera mount (1).stl, dual_camera_mount.stl]
2026-08-25 Rename currents CB LID (1).stl to Circuit_Box_LID.stl
    [Circuit_Box_LID.stl]
2026-08-25 Update test_results.csv with actual results
    [test_results.csv]
